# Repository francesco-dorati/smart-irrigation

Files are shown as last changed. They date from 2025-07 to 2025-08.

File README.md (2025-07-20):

# 🌿 Autonomous Plant Watering System

## Overview

This project aims to develop a **smart** and **autonomous** system for **watering indoor or outdoor plants**.  
The system is designed to **monitor soil moisture levels** and **automatically water** each plant when needed, making plant care effortless and reliable.

## 🌱 The Product

This system is designed to **take care of each plant separately** and **autonomously**.  
It provides **individualized watering** for each plant, ensuring they get exactly what they need—no more, no less.  
Perfect for balconies, gardens, or indoor setups.

1. **⚙️ Main Unit**  
   The central hub of the watering system, consisting of the **controller** and **water tank**.
   - 🪴 **Expandable** with up to **8 plants**  
   - 🔋 **Self-Sufficient** thanks to a **3500mAh battery**  
   - ☀️ **Solar Power** for complete autonomy

2. **🌿 Plant Unit**  
   A compact module attached to each plant, designed for **individual care**.
   - 📟 Composed of a **microcontroller**, **humidity sensor** and a **water pump**
   - 🔌 Connects to the Main Unit via an **Ethernet cable** and **water pipe**
   - 📏 Can be placed **up to 5 meters away** from the Main Unit

## 🚧 Project Status

- [x] Define system concept and design
- [x] Electrical scheme
- [x] Basic prototype
- [ ] Complete prototype with 1 plant
- [ ] Complete prototype with multiple plants
- [ ] Final enclosure design

## 📚 Resources
- ⚙️ Technical Details — [[here](docs/specifications.md)]
- 🧰  Components List — [[here](docs/components.md)]
- ⚡  Electrical Schemes — [[Main Unit](hardware/schematics/main_scheme.png) | [Plant Unit](hardware/schematics/plant_scheme.png)]
    
## 🤝 Contributing

Contributions, feedback, and suggestions are welcome!  
If you'd like to collaborate, please contact me via email:

**📧 fd.francescodorati@gmail.com**

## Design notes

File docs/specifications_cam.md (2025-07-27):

# Final Demo

## Main Loop:
1. **LOAD DATA**  
   - If `plants.csv`, `history.csv` or `weather.csv` is not in RAM, load them from SD card.  

     - **weather.csv** fields:  
       - `date` (YYYY-MM-DD)  
       - `T_max` (°C), `T_min` (°C)  
       - `Rn` (MJ/m²·day), `RH` (%)  
       - `u2` (m/s)

2. **TURN ON PLANTS**  
   - Activate the main relay (`RELAY_ON`).

3. **FOR EACH PLANT**  

   1. **STATUS REQUEST**  
      - Send `STATUS` → receive `<ID> <humidity> <saucerEmpty>`.

   2. **WATERING DECISION**  
      - **If** `saucerEmpty == true` (state `ABSORBING`): 

        1. **Compute reference evapotranspiration (ET₀)** using FAO Penman–Monteith:
           ```
           ET_{0} =
           (0.408 * Δ * (Rn - G) + (900/(T + 273)) * γ * u2 * (es - ea))
           / (Δ + γ * (1 + 0.34 * u2))
           ```
           - T = (T_max + T_min)/2  
           - G ≈ 0 (daily balance)  
           - Δ, γ, es, ea computed from T and RH.  

        2. **Select crop coefficient Kc** based on `type` and growth stage (use mid‑season Kc_mid by default):

           type            | Photosynthesis | Kc_mid
           ----------------|----------------|-------
           SUCCULENT       | CAM            | 0.30
           MEDITERRANEAN   | C3 (dry‑adapt) | 0.60
           HOUSEPLANT      | C3 (indoor)    | 0.80
           FERN            | C3 (humid)     | 1.00
           VEGETABLE       | C3/C4          | 1.10

        3. **Compute crop evapotranspiration**:
           ```
           ETc = Kc * ET0   [mm/day]
           ```
        4. **Convert ETc to water volume (ml)**:  
           - If saucer area A (m²) is known:
             ```
             water_ml = ETc [mm] * A [m2] * 1000
             ```
           - Otherwise scale by `saucerCapacity`:
             ```
             water_ml = saucerCapacity * (ETc / ET_ref)
             ```
             with ET_ref = 5 mm/day (approx. one full saucer).

        5. **Decision**: if `humidity <= minHumidity`, send  
           `WATER <water_ml>`  
           and set state = `WATERING`.

      - **Else if** state == `WATERING`:  
        1. **Check stop condition**: if  
           `humidity >= optimalHumidity * 0.9`  
           then send `WATER 0` (or `RELAY_OFF`) to stop.  
        2. **(Optional)**: recalculate ETc and adjust `water_ml` if continuing.

   3. **LOG**  
      - Append to `history.csv`: timestamp, `id`, `action`, `description`.

4. **WAKEUP DECISION**  
   - Based on predicted ET₀ for coming days (hot/dry → more frequent cycles), schedule next RTC wakeup.

5. **DEEP SLEEP**  
   - Enter deep sleep until RTC.

## Memory Files:
- `plants.csv`
    - `id`: id of the plant
    - `name`: name of the plant
    - `type`: type of plant
    - `saucerCapacity`: capacity of the saucer    
- `history.csv`
    - `time`: date time stamp
    - `id`: plant id or `-` for Main Unit
    - `action`: between `STATUS`, `WATER`, `WAKEUP`, `SLEEP`, `RELAY_ON`, `RELAY_OFF`
    - `description`: description of the action (status, uptime, etc)
- weather.csv
    - `date`,
    - `T_max`,
    - `T_min`,
    - `Rn`,
    - `RH`,
    - `u2`.

## Watering Process:

### Per-plant Data
 - `humidity`: current plant humidity (percentage)
 - `saucerEmpty`: wether saucer is empty
 - `saucerCapacity`: water capacity (or time to fill) of the plant saucer [ml or seconds]

### Type of Plants
  `SUCCULENT`, `FERN`, `HOUSEPLANT`, `MEDITERRANEAN`, `VEGETABLE`  
  Each of these plant types determines the values for these variables:
  - `minHumidity`: minimum soil humidity -> starts watering when reached
  - `optimalHumidity`: optimal soil humidity -> stops watering when reached
### Plant States
- `WATERING`: plant is being gradually watered (until humidity reaches `optimalHumidity`)
- `ABSORBING`: plant is absorbing water (waiting for humidity to reach `minHumidity`)

### Other External Data
- `temperature` (T_max, T_min)
- `airHumidity` (RH)
- `Rn`, `u2`

/* 
### Watering Process
The watering process proceeds gradually by filling the saucer by a specific amount and waiting for the plant to absorb it.
1. `SAUCER CHECK`: Check if the saucer is empty to receive water
  - if `ABSORBING` state:
    1. `CHECK`: Plant needs to be watered if `humidity <= minHumidity`
    2. `CALCULATE`: The amount of water to add is `saucerCapacity * (optimalHumidity - humidity)*2`
  - if `WATERING` state:
    1. `CHECK`: Plant needs to stop the watering process if `humidity >= optimalHumidity * 0.9`
    2. `CALCULATE`: The amount of water to add is `saucerCapacity * (optimalHumidity - humidity)*2`
*/

## Interfaces
- CLI -> Main Unit 
  - `INFO`: local info (without switching on plants)
  - `STATUS`: info about memory, and for each plant list current humidity and last watered time
  - `PLANT LIST`: list plants
  - `PLANT NEW`: new plant
  - `PLANT REMOVE`: remove plant
  - `PLANT INFO <id>`: prints local plant info
  - `PLANT STATUS <id>`: pings plant
  - `PLANT WATER <id>`: checks if plant needs water and if so waters it
    
- Main Unit -> Plant Unit
  - Status reading:  
      `STATUS` -> `<ID> <humidity> <saucerEmpty>`
  - Watering command:  
    `WATER <ml>` -> `<ID> DONE`
  - Humidity calibration  
    `HUMIDITY_CALIBRATION` -> `<ID> <sensor_voltage> <sensor_value>` 
  - Saucer capacity calibration:  
      `CAPACITY_CALIBRATION` -> `<ID> [OK/KO]`
    - Start calibration: `START`
    - Stop calibration: `STOP` -> `<ID> <ml>`        

## Future Predictions & AI
- Water consumption: use daily ETc to predict volumes.
- Saucer absorption: model rate based on T and RH.
- AI extensions: time-series ML or reinforcement learning for
optimization.

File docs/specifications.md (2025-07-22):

# Final Demo

## Main Loop:
1. `LOAD DATA`: if memory is empty load data from SD card
2. `TURN ON PLANTS`: turn the main realy on
3. for each plant:
    1. `STATUS REQUEST`: request plant status
    2. `WATERING DECISION`: decide if and how much water the plant
    3. `LOG`: log activities in `history.csv`
4. `WAKEUP DECISION`: decide when to wake up next
5. `DEEP SLEEP`: deep sleep until RTC wakeup call 

## Memory Files:
- `plants.csv`
    - `id`: id of the plant
    - `name`: name of the plant
    - `type`: type of plant
    - `saucerCapacity`: capacity of the saucer    
- `history.csv`
    - `time`: date time stamp
    - `id`: plant id or `-` for Main Unit
    - `action`: between `STATUS`, `WATER`, `WAKEUP`, `SLEEP`, `RELAY_ON`, `RELAY_OFF`
    - `description`: description of the action (status, uptime, etc)

## Watering Process:

### Data for each Plant
 - `humidity`: current plant humidity (percentage)
 - `saucerEmpty`: wether saucer is empty
 - `saucerCapacity`: water capacity (or time to fill) of the plant saucer [ml or seconds]

### Type of Plants
  `SUCCULENT`, `FERN`, `HOUSEPLANT`, `MEDITERRANEAN`, `VEGETABLE`  
  Each of these plant types determines the values for these variables:
  - `minHumidity`: minimum soil humidity -> starts watering when reached
  - `optimalHumidity`: optimal soil humidity -> stops watering when reached
### Plant States
- `WATERING`: plant is being gradually watered (until humidity reaches `optimalHumidity`)
- `ABSORBING`: plant is absorbing water (waiting for humidity to reach `minHumidity`)

### Other External Data
- `temperature`: outside temperature
- `airHumidity`: outside air humidity

### Watering Process
The watering process proceeds gradually by filling the saucer by a specific amount and waiting for the plant to absorb it.
1. `SAUCER CHECK`: Check if the saucer is empty to receive water
  - if `ABSORBING` state:
    1. `CHECK`: Plant needs to be watered if `humidity <= minHumidity`
    2. `CALCULATE`: The amount of water to add is `saucerCapacity * (optimalHumidity - humidity)*2`
  - if `WATERING` state:
    1. `CHECK`: Plant needs to stop the watering process if `humidity >= optimalHumidity * 0.9`
    2. `CALCULATE`: The amount of water to add is `saucerCapacity * (optimalHumidity - humidity)*2`
       
## Interfaces
- CLI -> Main Unit 
  - `INFO`: local info (without switching on plants)
  - `STATUS`: info about memory, and for each plant list current humidity and last watered time
  - `PLANT LIST`: list plants
  - `PLANT NEW`: new plant
  - `PLANT REMOVE`: remove plant
  - `PLANT INFO <id>`: prints local plant info
  - `PLANT STATUS <id>`: pings plant
  - `PLANT WATER <id>`: checks if plant needs water and if so waters it
    
- Main Unit -> Plant Unit
  - Status reading:  
      `STATUS` -> `<ID> <humidity> <saucerEmpty>`
  - Watering command:  
    `WATER <ml>` -> `<ID> DONE`
  - Humidity calibration  
    `HUMIDITY_CALIBRATION` -> `<ID> <sensor_voltage> <sensor_value>` 
  - Saucer capacity calibration:  
      `CAPACITY_CALIBRATION` -> `<ID> [OK/KO]`
    - Start calibration: `START`
    - Stop calibration: `STOP` -> `<ID> <ml>`        

## Preditions:
- predict water consumption by plant, given plant info and temperature
- predict saucer water absobtion given outside temperature, humidity

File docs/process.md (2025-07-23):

## Operative Process:
1. Test current setup with MOSFET instead of relay
2. Finalize Plant Unit design
3. Main Unit breadboard setup
4. Testig and logic implementations
5. Finalize Main Unit design
6. PCB design

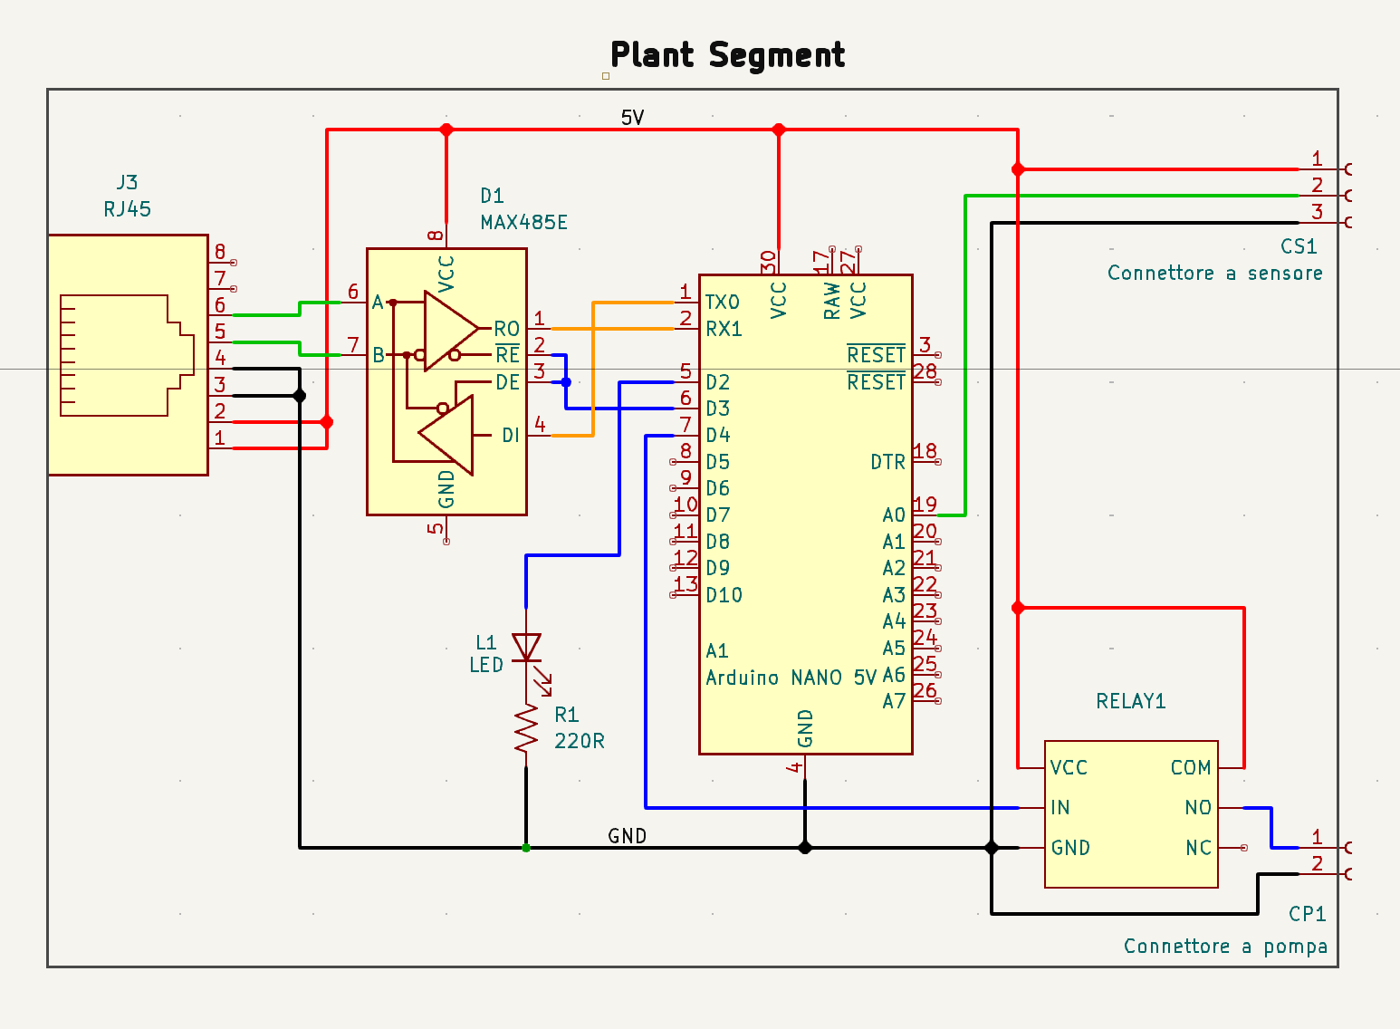
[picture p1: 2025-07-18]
hardware/schematics/plant_scheme.png

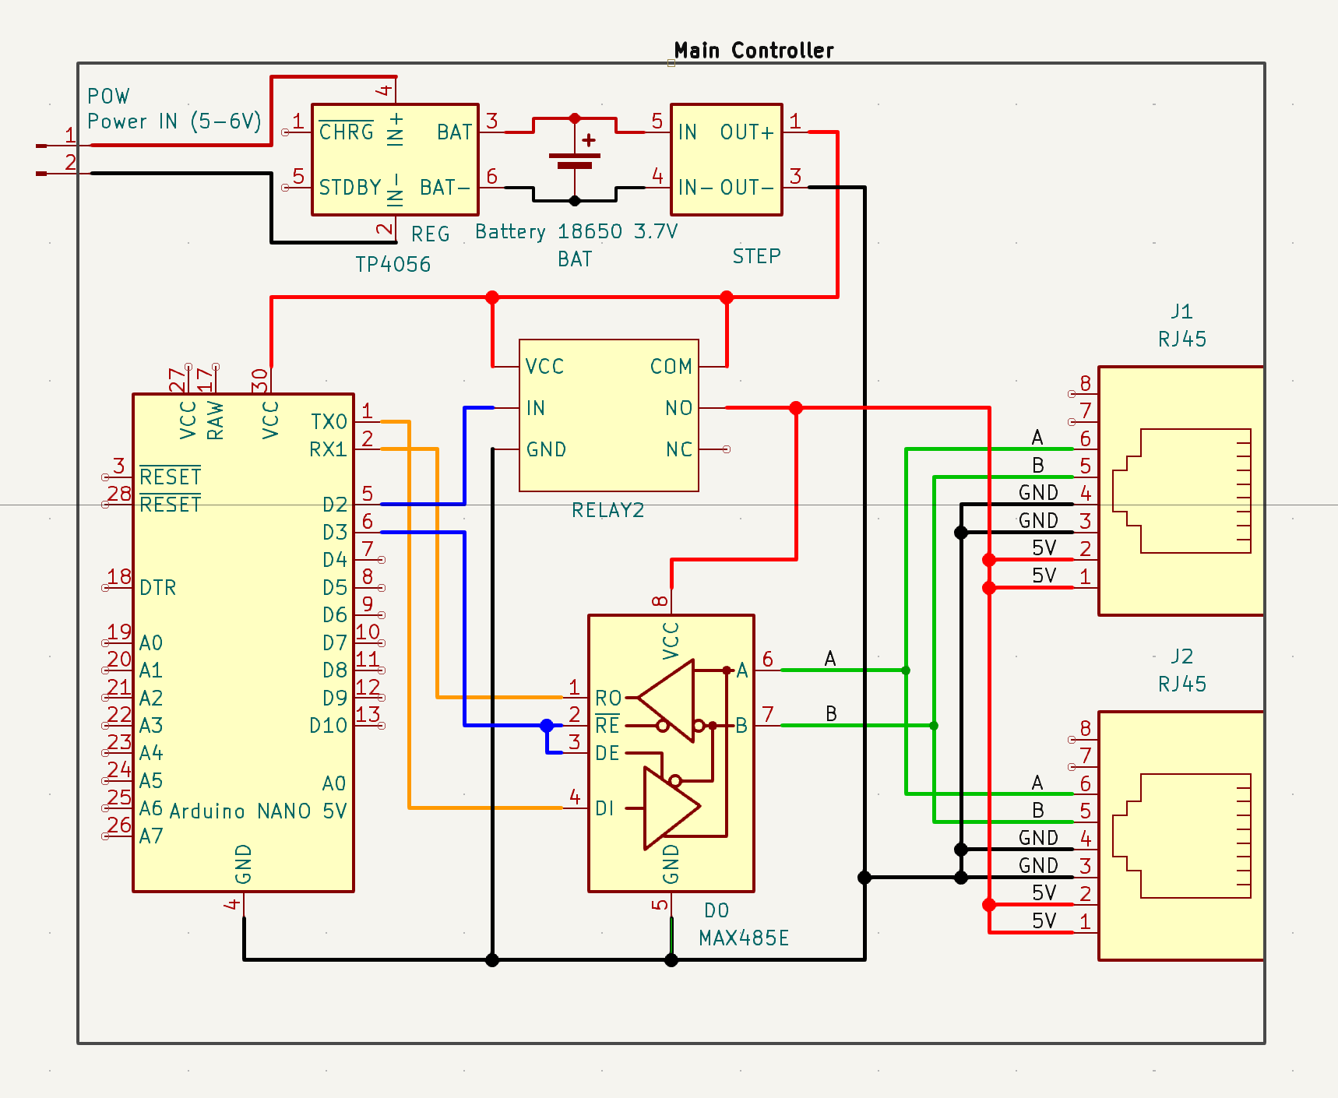
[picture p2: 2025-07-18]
hardware/schematics/main_scheme.png

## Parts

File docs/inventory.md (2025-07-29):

### Order 1 [06/07/2025]
- 5x Humidity Sernsor 
- 1x Pump
- 1x USB-Serial Converter
- 1x Ethernet Cable
- 2x Pro Mini Microcontroller 3.3V
- 2x Ethernet Adapter
- 10x MAX485 Connection Module
- **subtotal: 20€**

### Order 2 [20/07/2025]
- 1x RTC Module
- 5x Battery Charger Module TP4056
- 1x Relay Module
- 4x PCB Boards
- 1x ESP32 Board
- 5x DC-DC Step Up
- 1x Battery Support
- 1x Pipe
- 3x Ethernet Adapter
- 1x Battery 18560
- **subtotal: 38€**

### Order 3 [22/07/2025]
- 10x Screw Terminal 2-pin
- 10x Screw Terminal 3-pin
- 10x N MOSFET IRLZ44N
- 50x Diode 1N4007
- 300x Resistors (various)
- **subtotal: 12€**
  
### Order 4 [29/07/2025]
- 50x NPN MOSFET 2N2222
- 10x P MOSFET IRF4905
- **subtotal: 14€**

---
### Total Euro: 84€

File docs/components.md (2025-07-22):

# Components
TODO: Update the realy with mosfet
### **Per Pianta:**  

  → 4 cavi dal Main: 5V, GND, A, B  -> Cavo ETHERNET
- [ ]  1 Humidity Sensor analogical capacitive (3-5V, ? W, DC) [SZHJW]
- [ ]  1 Pump (3-5V, 0.91W max, DC)
- [ ]  1 Microcontroller Arduino NANO (5V, ? W, DC)
- [ ]  1 Relay Module [SRD-05VDC-SL-C]
- [ ]  1 Connection Module [MAX485 TTL]
- [ ]  1 Resistor 10k 
- [ ]  1 Cavo Ethernet 3m
- [ ]  1 Connettore Ethernet
- [ ]  1 Tubo acqua 

---

### **Control Unit:**

**Controller:**

- [ ]  1 Microcontroller ESP32 (5V, ? W, DC)
- [ ]  1 Connection Module [MAX485] 
- [ ]  1 MicroSD Module 
- [ ]  1 Relay Module [SRD-05VDC-SL-C]
- [ ]  1 Ethernet Connector
- [ ]  1 Temperature Sensor
- [ ]  1 RTC Module

**Power Management:**

- [ ]  1 Modulo caricatore batteria (5V, 1A, DC)[TP4056]
- [ ]  1/2 Batterie 18650  (3.7V, 2500–3000mAh)
- [ ]  1 Step-Up MT3608 (3.7V → 5V, 2A out max)

**Altro:**

- [ ]  1 Pannello solare (5-6V, 2W)

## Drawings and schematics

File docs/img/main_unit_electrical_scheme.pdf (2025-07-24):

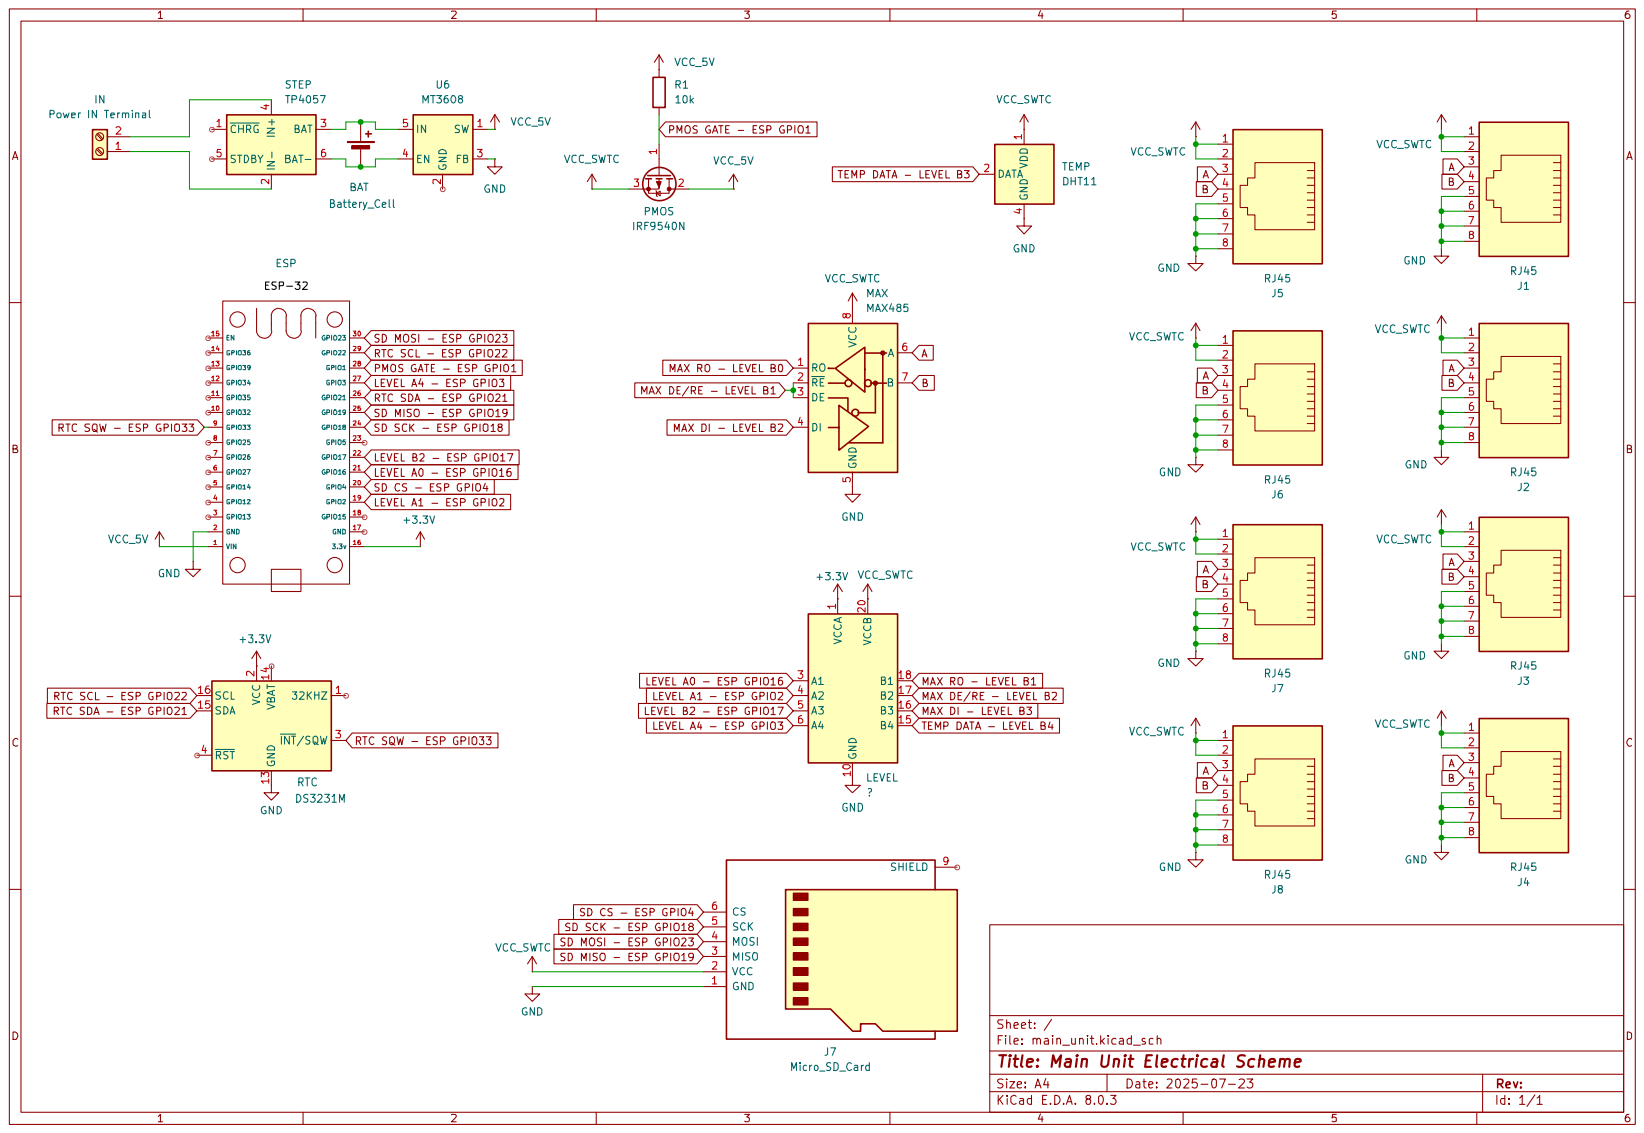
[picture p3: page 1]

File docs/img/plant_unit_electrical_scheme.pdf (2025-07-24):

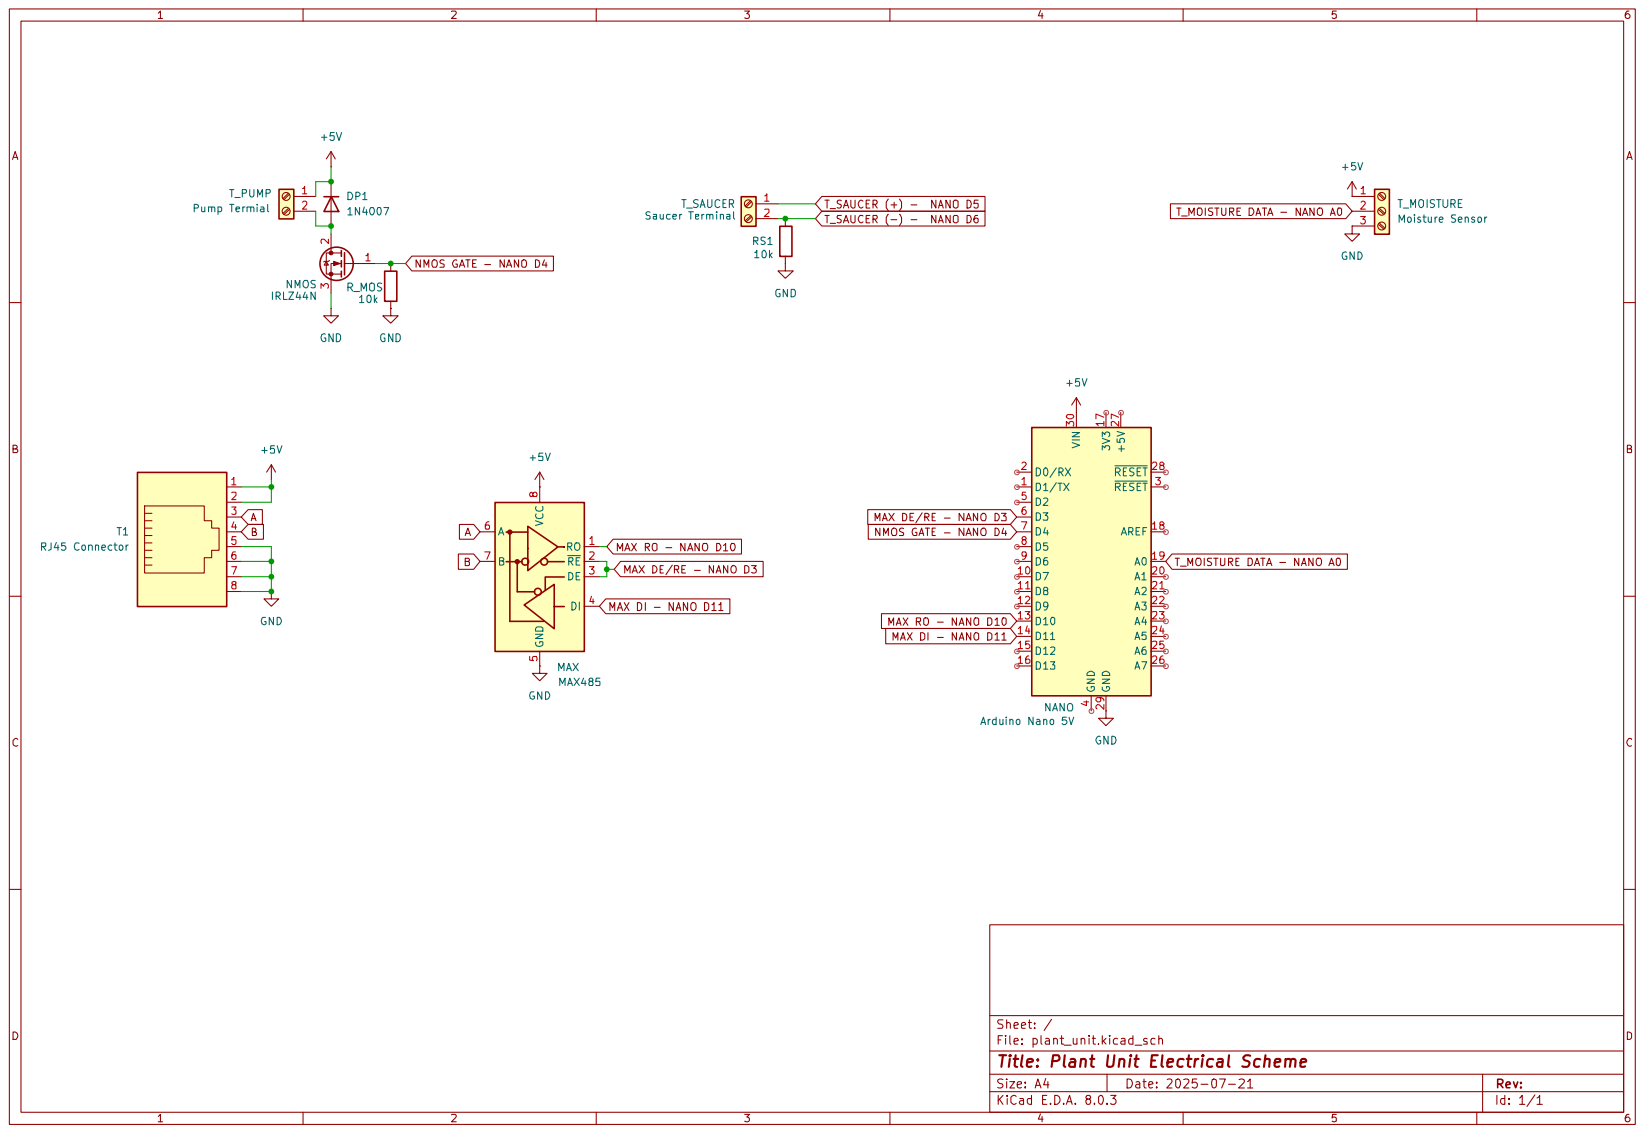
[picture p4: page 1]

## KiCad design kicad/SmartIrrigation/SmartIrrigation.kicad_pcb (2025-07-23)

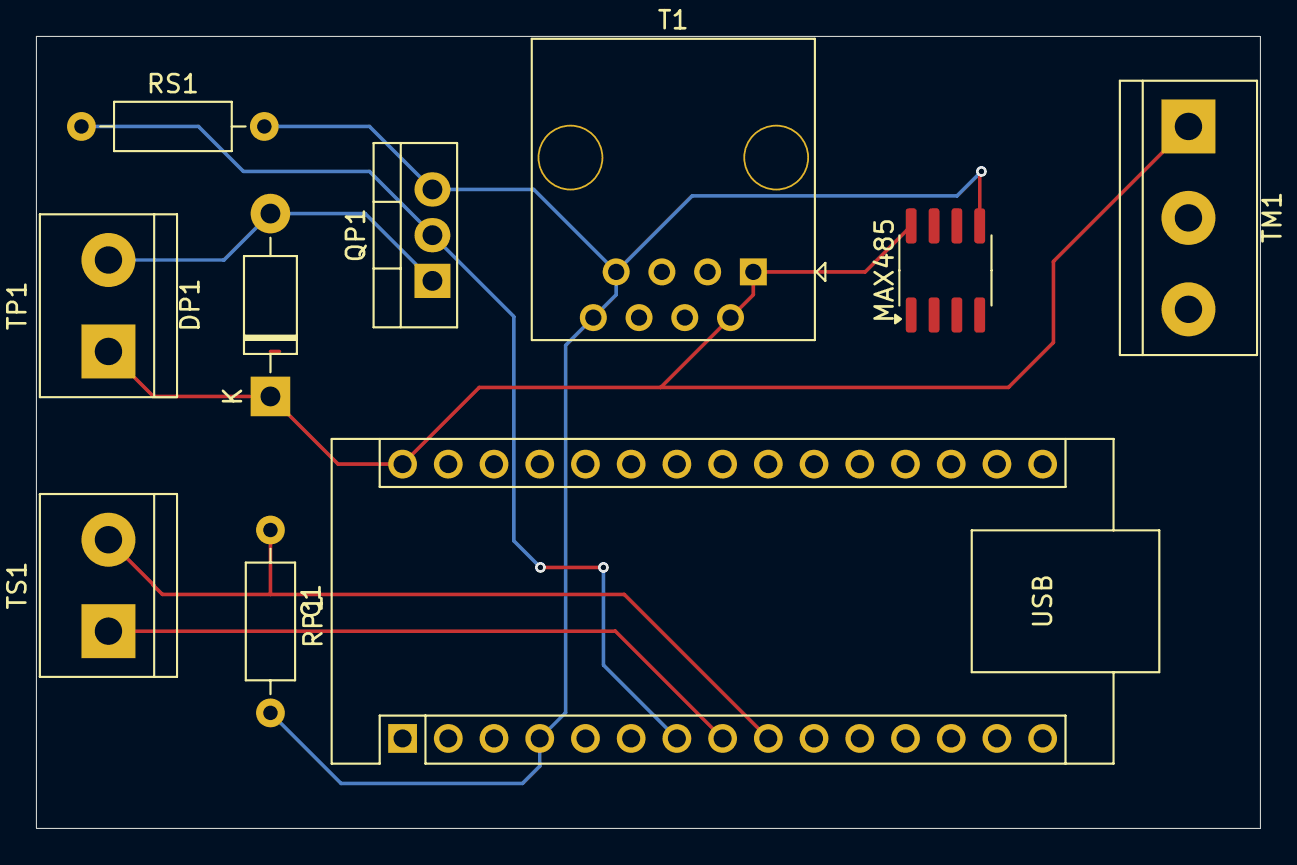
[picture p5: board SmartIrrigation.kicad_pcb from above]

Board: 2 copper layers, 68.0 x 44.0 mm, 10 parts (0 on the bottom side), 12 nets.

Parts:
C1: Arduino Nano 5V; Arduino_Nano
DP1: 1N4007; D_DO-41_SOD81_P10.16mm_Horizontal
MAX485: Connection Module; SOIC-8_3.9x4.9mm_P1.27mm
QP1: IRLZ44N; TO-220-3_Vertical
RP1: 10k; R_Axial_DIN0207_L6.3mm_D2.5mm_P10.16mm_Horizontal
RS1: 10k; R_Axial_DIN0207_L6.3mm_D2.5mm_P10.16mm_Horizontal
T1: RJ45 Connector; RJ45_OST_PJ012-8P8CX_Vertical
TM1: Moisture Sensor; TerminalBlock_bornier-3_P5.08mm
TP1: Pump Termial; TerminalBlock_bornier-2_P5.08mm
TS1: Saucer Terminal; TerminalBlock_bornier-2_P5.08mm

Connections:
+5V: C1.30 (VIN), DP1.1 (K), MAX485.8 (VCC), T1.1, T1.2, TM1.1, TP1.1
GND: C1.4 (GND), MAX485.5 (GND), QP1.3 (S), RP1.2, RS1.2, T1.7, T1.8, TM1.3
unnamed: C1.19 (A0), TM1.2
unnamed: C1.6 (D3), MAX485.2 (~RE), MAX485.3 (DE)
unnamed: C1.7 (D4), QP1.2 (D), RS1.1
unnamed: C1.8 (D5), TS1.1
unnamed: C1.9 (D6), RP1.1, TS1.2
unnamed: C1.13 (D10), MAX485.1 (RO)
unnamed: C1.14 (D11), MAX485.4 (DI)
unnamed: DP1.2 (A), QP1.1 (G), TP1.2
unnamed: MAX485.6 (A), T1.3
unnamed: MAX485.7 (B), T1.4

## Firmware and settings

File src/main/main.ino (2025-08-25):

#include <Arduino.h>
#include <ArduinoOTA.h>

#include "Controller.h"
#include "WiFiManager.h"

WiFiManager wifi("iPhone di Francesco", "grinder420");
Controller controller(wifi);

void setup() {
  Serial.begin(115200);
  wifi.begin();
  delay(2000);
  controller.init();
  delay(1000);

  ArduinoOTA.setHostname("smart-irrigation"); // Optional
  ArduinoOTA.begin();

  wifi.println("\n\n\n--- SMART IRRIGATION ---\n");
  status();
  help();
  prompt();
}

void loop() {
  ArduinoOTA.handle();

  // Serial command
  if (Serial.available()) {
    String command = readCommand();
    if (!command.equals("")) {
      interpretUserCommand(command);
    }
  }

  if (wifi.available()) {
    String command = wifi.getCommand();
    if (!command.equals("")) {
      interpretUserCommand(command);
    }
  }
}

String readCommand() {
    String command = Serial.readStringUntil('\n');
    command.trim();
    command.toUpperCase(); 
    return command;
}

void interpretUserCommand(String command) {
  wifi.println("");
  String a0 = getArg(command, 0);
  if (a0.equals("PLANT") || a0.equals("P")) {

    String a1 = getArg(command, 1);
    if (a1.equals("NEW") || a1.equals("N")) {  // PLANT NEW <id> <name>
      // ON command (sd)
      newPlant();

    } else if (a1.equals("LIST") || a1.equals("L")) {  // PLANT LIST
      // OFF command
      listPlants();

    } else if (a1.equals("INFO") || a1.equals("I")) {  // PLANT INFO <id>
      // OFF command
      int plantId = getArg(command, 2).toInt();
      infoPlant(plantId);

    } else if (a1.equals("STATUS") || a1.equals("S")) {  // PLANT STATUS <id> 
      int plantId = getArg(command, 2).toInt();
      statusPlant(plantId);

    } else if (a1.equals("WATER") || a1.equals("W")) {  // PLANT WATER <id>
      int plantId = getArg(command, 2).toInt();
      waterPlant(plantId);

    } else {
      help();
    }

  } else if (a0.equals("STATUS") || a0.equals("S")) {
    status();

  } else if (a0.equals("INFO") || a0.equals("I")) {
    info();

  } else if (a0.equals("ON") || a0.equals("1")) {
    wifi.println("Powering ON");
    controller.turnOn();

  } else if (a0.equals("OFF") || a0.equals("0")) {
    wifi.println("Powering OFF");
    controller.turnOff();

  } else if (a0.equals("SLEEP") || a0.equals("Z")) {
    int sleepTime = getArg(command, 1).toInt();
    if (sleepTime <= 0) {
      wifi.println("Invalid sleep time. Please specify a positive number.");
      return;
    }
    controller.sleep(sleepTime);

  } else {
    help();
  }

  prompt();
}

String getArg(String command, int argIndex) {
  for (int i = 0; i <= argIndex; i++) {
    int spaceIndex = command.indexOf(' ');
    if (spaceIndex == -1) {
      if (i == argIndex)
        return command;  // Last argument
      else
        return "";  // Not enough arguments
    }
    if (i == argIndex) {
      return command.substring(0, spaceIndex);
    }
    command = command.substring(spaceIndex + 1);
  }
  return "";
}



// SERIAL DEBUG COMMANDS
void newPlant() {
  wifi.println("\n\n--- PLANT CREATION ---\n");

  // ID
  int plantId;
  wifi.println("\nPlease enter the plant ID: ");
  while (!wifi.available());
  String plantIdString = wifi.getCommand();
  plantId = plantIdString.toInt();

  // NAME
  String plantName;
  wifi.println("\nPlease enter the plant name: ");
  while (!wifi.available());
  plantName = wifi.getCommand();

  // TYPE (WATER PREFERENCE)
  WaterPreference waterPreference;
  int typeCount = sizeof(WaterPreference::allTypes) / sizeof(WaterPreference*);
  int typeSelection;
  do {
    wifi.println("\nPlease choose the plant type:");
    for (int i = 1; i <= typeCount; i++) {
      const WaterPreference* type = WaterPreference::allTypes[i-1];
      wifi.println("\t[" + String(i) + "] " + type->toString() + 
                   " (Min: " + String((int)type->minHumidity) + "%, Optimal: " + String((int)type->optimalHumidity) + "%)");
    }
    wifi.println("\t[0] CUSTOM");

    wifi.println("\nEnter the number corresponding to the plant type: ");
    while (!wifi.available());
    String typeSelectionString = wifi.getCommand();
    typeSelection = typeSelectionString.toInt();
  } while (typeSelection < 0 || typeSelection > typeCount);

  if (typeSelection == 0) {
    // CUSTOM type selected
    // min humidity
    wifi.println("\nPlease enter the minimum humidity value (in %): ");
    while (!wifi.available());
    String minHumidityString = wifi.getCommand();
    float minHumidity = minHumidityString.toFloat();
    // optimal humidity
    wifi.println("\nPlease enter the optimal humidity value (in %): ");
    while (!wifi.available());
    String optimalHumidityString = wifi.getCommand();
    float optimalHumidity = optimalHumidityString.toFloat();
    // preference creation
    waterPreference = WaterPreference(minHumidity, optimalHumidity, "CUSTOM");
  } else {
    // preference selection
    waterPreference = *WaterPreference::allTypes[typeSelection - 1];
  }

  // SAUCER CAPACITY
  int saucerCapacity;
  // @TODO SAUCER CAPACITY TEST
  wifi.println("\nPlease enter the saucer capacity (in ml): ");
  while (!wifi.available());
  String saucerCapacityString = wifi.getCommand();
  saucerCapacity = saucerCapacityString.toInt();

  // PLANT OVERVIEW
  wifi.println("\n--- PLANT OVERVIEW ---\n");
  wifi.println("ID: " + String(plantId));
  wifi.println("Name: " + plantName);
  wifi.println("Type: " + waterPreference.toString() + 
               " (Min: " + String((int)waterPreference.minHumidity) + "%, Optimal: " + String((int)waterPreference.optimalHumidity) + "%)");
  wifi.println("Saucer Capacity: " + String(saucerCapacity) + " ml");

  // CONFIRMATION
  wifi.println("\nDo you want to proceed with the creation? (y/n)");
  while (!wifi.available());
  String confirmation = wifi.getCommand();
  confirmation.toLowerCase();
  if (!confirmation.equals("y") && !confirmation.equals("yes")) {
    wifi.println("\nPlant creation cancelled.");
    return;
  }

  // PLANT CREATION
  bool ok = controller.addPlant(plantId, plantName, waterPreference, saucerCapacity);
  if (ok) {
    wifi.println("\nPlant created successfully!");
  } else {
    wifi.println("\nFailed to create plant.");
  }
}

void info() {
  wifi.println("\n--- SYSTEM INFO ---\n");
  wifi.println("SD Card: " + String(controller.getSDCard().getFreeSpace()) + " GB free (" + String(controller.getSDCard().getTotalSpace()) + " GB total)");
  wifi.println("Current time: " + controller.getReadableTimeString());
  wifi.println("Battery: -- %");
  wifi.println("Uptime: -- min");
  wifi.println("\nYOUR PLANTS:");
  Plant** plants = controller.getPlants();
  for (int i = 0; i < MAX_PLANTS; i++) {
    if (plants[i] != nullptr) {
      String infoString = controller.getPlantInfoString(plants[i]->getId());
      wifi.println(infoString);
    }
  }
}

void statusPlant(int id) {
  String statusString = controller.getPlantStatusString(id);
  wifi.println(statusString);
}

void infoPlant(int id) {
  String infoString = controller.getPlantInfoString(id);
  wifi.println(infoString);
}

void waterPlant(int id) {
  Plant* plant = controller.getPlant(id);
  if (plant == nullptr) {
    wifi.println("Plant " + String(id) + " not found");
    return;
  }

  wifi.println("Watering " + plant->getName() + "...");
  bool ok = plant->water(30);
  if (ok) {
    wifi.println("Watering completed successfully");
  } else {
    wifi.println("Failed to water " + plant->getName());
  }
}

void status() {
  wifi.println("\n--- STATUS ---\n");
  wifi.println(controller.getEnvironmentDataString()+"\n");
  wifi.println("YOUR PLANTS:");
  Plant** plants = controller.getPlants();
  for (int i = 0; i < MAX_PLANTS; i++) {
    if (plants[i] != nullptr) {
      String statusString = controller.getPlantStatusString(plants[i]->getId());
      wifi.println(statusString);
    }
  }
}

void help() {
  wifi.println("\n--- AVAILABLE COMMANDS ---\n");
  wifi.println("\tINFO - Show local information (battery, uptime, etc.)");
  wifi.println("\tON/OFF - Turn on/off the system");
  wifi.println("\tSTATUS - Show the status of all plants");
  wifi.println("\tSLEEP <sec> - Put the system to sleep for a specified number of seconds");
  //Serial.println("");
  wifi.println("\tPLANT LIST - List all plants");
  wifi.println("\tPLANT NEW - Create a new plant");
  wifi.println("\tPLANT REMOVE <id> - Remove plant with the given id");
  wifi.println("\tPLANT INFO <id> - Get information about a specific plant");
  wifi.println("\tPLANT STATUS <id> - Get the status of a specific plant");
  wifi.println("\tPLANT WATER <id> - Water a specific plant");
}

void prompt() {  
  String s = "\n";
  s += controller.getReadableTimeString();
  
  s += " | Power ";
  s += controller.isOn() ? "ON" : "OFF";
  
  s += " | WiFi ";
  s += wifi.isConnected() ? "CONNECTED" : "DISCONNECTED";

  s += "\n> ";

  wifi.print(s);

}

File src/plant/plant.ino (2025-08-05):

#include <Arduino.h>

#include "HumiditySensor.h"
#include "LED.h"
#include "Pump.h"
#include "RS485Client.h"
#include "SaucerSensor.h"

const int PLANT_ID = 0;  // Unique ID for this plant

const int SENSOR_PIN = A0;
const int LED_PIN = 2;
const int COMM_PIN = 3;  // LOW: listening, HIGH: sending
const int PUMP_PIN = 4;  // LOW: ON, HIGH: OFF
const int SAUCER_POWER_PIN = 5; // OUTPUT LOW: POWER OFF, HIGH: POWER ON
const int SAUCER_READING_PIN = 6; // INPUT LOW: EMPTY, HIGH: FULL
const int RX_PIN = 11;   // RX pin for RS485
const int TX_PIN = 10;   // TX pin for RS485

RS485Client rs485(PLANT_ID, COMM_PIN, RX_PIN, TX_PIN);
LED led(LED_PIN);
HumiditySensor humiditySensor(SENSOR_PIN);
SaucerSensor saucerSensor(SAUCER_POWER_PIN, SAUCER_READING_PIN);
Pump pump(PUMP_PIN);

void setup() {
  Serial.begin(9600);

  rs485.begin(9600);
  led.begin();
  humiditySensor.begin();
  saucerSensor.begin();
  pump.begin();

  led.blink();
  led.blink();
  Serial.println("START");
  delay(1000);
}

void loop() {
  // RS485 communication
  if (rs485.available()) {
    // Read command from RS485
    String command = rs485.receiveCommand();
    if (!command.equals("")) {
      interpretCommand(command);
    }
  }

  // Serial communication (DEBUG)
  if (Serial.available()) {
    String command = Serial.readStringUntil('\n');
    Serial.println("debugging: \"" + command + "\"");
    interpretDebug(command);
  }
}

void interpretCommand(String command) {

  if (command.equals("PING")) {
    led.blink();
    rs485.transmit("PONG");

  } else if (command.startsWith("WATER")) {
    int seconds = command.substring(6).toInt();
    if (seconds < 0) return;  // Invalid command
    pump.activate(seconds);
    rs485.transmit("DONE");

  } else if (command.startsWith("STATUS")) { 
    float humidity = humiditySensor.getHumidity();
    bool full = saucerSensor.isFull();
    String status = String(humidity) + " " + (full ? "1" : "0");
    rs485.transmit(status);

  } else {
    Serial.println("Unknown command: \"" + command + "\"");
  }
}

void interpretDebug(String command) {
  if (command.equals("PING")) {
    led.blink();
    Serial.println("PONG");
  } else if (command.equals("HUMIDITY")) {
    int value = humiditySensor.getValue();
    float voltage = humiditySensor.getVoltage();
    int humidity = humiditySensor.getHumidity();
    Serial.println("Humidity: " + String(humidity) + "%, Voltage: " +
                   String(voltage) + "V, value: " + String(value));
  } else if (command.startsWith("WATER")) {
    int seconds = command.substring(6).toInt();
    if (seconds < 0) return;  // Invalid command
    pump.activate(seconds);
    Serial.println("Watering DONE.");
  } else {
    Serial.println("Unknown command: " + command);
  }
}

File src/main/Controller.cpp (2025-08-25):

#include "Controller.h"

Controller::Controller(WiFiManager& wifi_)
    : wifi(wifi_),
      isPowerOn(false),
      tempSensor(DHT_PIN, DHT11),
      rs485(COMM_PIN, RX_PIN, TX_PIN, 9600),
      sdCard(SD_CARD_CS_PIN, SD_CARD_SCK_PIN, SD_CARD_MISO_PIN,
             SD_CARD_MOSI_PIN) {}

void Controller::init() {
  pinMode(LED_BUILTIN, OUTPUT);
  pinMode(POWER_PIN, OUTPUT);          // Set pin to LOW to avoid floating state
  pinMode(SHIFTER_POWER_PIN, OUTPUT);  // Set pin to LOW to avoid floating state
  pinMode(RTC_WAKEUP_PIN, INPUT_PULLUP);
  pinMode(BUTTON_WAKEUP_PIN, INPUT);

  digitalWrite(LED_BUILTIN, LOW);
  digitalWrite(POWER_PIN, LOW);          // Ensure pin is LOW initially
  digitalWrite(SHIFTER_POWER_PIN, LOW);  // Ensure pin is LOW initially
  // RTC begin
  if (!rtc.begin()) {
    wifi.println("Couldn't find RTC");
    while (1);
  }
  if (rtc.lostPower()) {
    wifi.println("RTC lost power, setting the time!");
    // Set time only the first time or after battery loss
    rtc.adjust(DateTime(F(__DATE__), F(__TIME__)));
  }

  // /* remove */ plants[0] =
  //     new Plant(rs485, 0, "Test Plant", PlantState::ABSORBING,
  //               WaterPreference::MEDITERRANEAN, 100);
}

bool Controller::addPlant(int id, String name, WaterPreference waterPreference,
                          int saucerCapacity) {
  turnOn();
  // Check if plant with same ID already exists
  for (int i = 0; i < MAX_PLANTS; i++) {
    if (plants[i] != nullptr && plants[i]->getId() == id) {
      wifi.println("ERROR: Plant with ID " + String(id) + " already exists.");
      return false;
    }
  }

  // Find an empty slot for the new plant
  for (int i = 0; i < MAX_PLANTS; i++) {
    if (plants[i] == nullptr) {
      Plant* newPlant = new Plant(rs485, id, name, PlantState::ABSORBING,
                                  waterPreference, saucerCapacity);
      if (!newPlant->ping()) {
        wifi.println("ERROR: No response from plant with ID " + String(id));
        delete newPlant;  // Clean up
        return false;
      }
      plants[i] = newPlant;
      sdCard.addPlant(newPlant);  // Save to SD card
      return true;                // Successfully added
    }
  }

  wifi.println("ERROR: Maximum number of plants reached.");
  return false;  // No empty slot found
}

Plant* Controller::getPlant(int id) {
  turnOn();
  for (int i = 0; i < MAX_PLANTS; i++) {
    if (plants[i] != nullptr && plants[i]->getId() == id) {
      return plants[i];
    }
  }
  return nullptr;  // Plant not found
}

Plant** Controller::getPlants() {
  return plants;  // Return the array of plant pointers
}

bool Controller::isOn() { return isPowerOn; }

void Controller::turnOn() {
  pinMode(POWER_PIN, OUTPUT);  // Set pin to OUTPUT to control power
  digitalWrite(POWER_PIN, HIGH);

  pinMode(SHIFTER_POWER_PIN, OUTPUT);
  digitalWrite(SHIFTER_POWER_PIN, HIGH);

  // Allow some time for the power to turn on
  if (!isPowerOn) {
    // Powering on the system
    delay(2000);  // Allow some time for the power to stabilize
    rs485.start();
    tempSensor.begin();
    if (!sdCard.start()) {
      wifi.println("ERROR: SD Card not found!");
    }
    rtc.begin();
    delay(1000);
  }
  isPowerOn = true;
}

void Controller::turnOff() {
  digitalWrite(SHIFTER_POWER_PIN, LOW);  // Turn off power
  delay(10);

  digitalWrite(POWER_PIN, LOW);  // Turn off power
  delay(10);

  if (isPowerOn) {
    rs485.stop();
    sdCard.stop();
    pinMode(DHT_PIN, INPUT);
    digitalWrite(DHT_PIN, LOW);
    rtc.begin();  // Reinitialize RTC because sd card fails it
  }

  isPowerOn = false;
}

void Controller::sleep(int seconds) {
  turnOff();

  rtc_gpio_init((gpio_num_t)SHIFTER_POWER_PIN);
  rtc_gpio_set_direction((gpio_num_t)SHIFTER_POWER_PIN,
                         RTC_GPIO_MODE_OUTPUT_ONLY);
  rtc_gpio_set_level((gpio_num_t)SHIFTER_POWER_PIN, 0);

  rtc_gpio_init((gpio_num_t)POWER_PIN);
  rtc_gpio_set_direction((gpio_num_t)POWER_PIN, RTC_GPIO_MODE_OUTPUT_ONLY);
  rtc_gpio_set_level((gpio_num_t)POWER_PIN, 0);

  // Clear any existing alarms
  rtc.disableAlarm(1);
  rtc.clearAlarm(1);

  DateTime now = rtc.now();
  rtc.setAlarm1(now + TimeSpan(0, 0, 0, seconds), DS3231_A1_Second);

  // Configure wakeup from external pin
  esp_sleep_enable_ext0_wakeup(RTC_WAKEUP_PIN, 0);  // Wake when pin goes LOW
  esp_sleep_enable_ext1_wakeup((1ULL << BUTTON_WAKEUP_PIN),
                               ESP_EXT1_WAKEUP_ANY_HIGH);

  wifi.println("Going to sleep for " + String(seconds) + " seconds...");
  delay(1000);

  esp_deep_sleep_start();
}

SDCard& Controller::getSDCard() {
  return sdCard;
}

String Controller::getTimeString() {
  DateTime now = rtc.now();
  char buf[20];  // enough space for "yyyy-mm-dd hh:mm:ss"
  sprintf(buf, "%04d-%02d-%02d %02d:%02d:%02d", now.year(), now.month(),
          now.day(), now.hour(), now.minute(), now.second());
  return String(buf);
}

String Controller::getReadableTimeString() {
  DateTime now = rtc.now();
  const char* months[] = {"Jan", "Feb", "Mar", "Apr", "May", "Jun",
                          "Jul", "Aug", "Sep", "Oct", "Nov", "Dec"};
  char buf[50];  // enough space for "dd Month yyyy hh:mm"
  snprintf(buf, sizeof(buf), "%d %s %04d %02d:%02d", now.day(),
           months[now.month() - 1], now.year(), now.hour(), now.minute());
  return String(buf);
}

String Controller::getEnvironmentDataString() {
  turnOn();
  float humidity = tempSensor.readHumidity();
  float temperature = tempSensor.readTemperature();

  if (isnan(humidity) || isnan(temperature)) {
    return "Failed to read from DHT sensor!";
  }

  return "Temperature: " + String((int)temperature) +
         "°C\nAir Humidity: " + String((int)humidity) + "%";
}

String Controller::getPlantStatusString(int id) {
  turnOn();
  String s = "";
  Plant* plant = getPlant(id);
  if (plant == nullptr) {
    s += "\n\t\tCurrently OFFLINE.";
    return s;
  }

  bool status = plant->loadStatus();

  String humidity = String((int)(plant->getHumidity() * 100));
  String saucerFull = plant->isSaucerFull() ? "FULL" : "EMPTY";
  int waterNeeded = plant->checkWaterNeeds(plant->getHumidity());

  s += "\t- [" + String(plant->getId()) + "] " + plant->getName();
  if (status) {
    s += "\n\t\tHumidity: \t" + humidity + "%";
    s += "\n\t\tSaucer: \t" + saucerFull;
    s += "\n\t\tNeeds Water: \t" +
         ((waterNeeded > 0) ? "YES, " + String(waterNeeded) + " %" : "NO");
  } else {
    s += "\n\t\tCurrently OFFLINE.";
  }

  return s;
}
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

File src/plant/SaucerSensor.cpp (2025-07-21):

#include "SaucerSensor.h"

SaucerSensor::SaucerSensor(int powerPin, int readingPin)
    : powerPin(powerPin), readingPin(readingPin) {}

void SaucerSensor::begin() {
  pinMode(powerPin, OUTPUT);
  pinMode(readingPin, INPUT);
  digitalWrite(powerPin, LOW);
}

bool SaucerSensor::isFull() {
  digitalWrite(powerPin, HIGH);
  delay(100);
  bool full = digitalRead(readingPin) == HIGH;
  digitalWrite(powerPin, LOW);
  return full;
}

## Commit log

2025-06-29 created folders
    [scheme.kicad_sch]
2025-06-29 changed schema
    [scheme.kicad_sch]
2025-06-29 plant client schema almost complete
    [scheme.kicad_sch]
2025-06-29 base schematics added
    [scheme.kicad_sch]
2025-06-30 modified base schematics
2025-07-05 modified schematics
    [scheme.kicad_sch]
2025-07-17 created basic prototype
2025-07-18 saved schematics & formatted
    [scheme.kicad_sch]
2025-07-20 Refactor LED blink method and implement RTC and RS485 communication classes
2025-07-21 Add SaucerSensor class and electrical scheme for plant unit
    - Implemented SaucerSensor class with methods to initialize and check if the saucer is full.
    - Added initial electrical scheme for the plant unit in KiCad.
    [SmartIrrigation.kicad_pcb, SmartIrrigation.kicad_sch, main_unit.kicad_sch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]
2025-07-21 Modifica il tipo di ID da String a int in diverse classi e aggiorna i metodi di ricezione e trasmissione per riflettere il cambiamento
2025-07-23 Add SDCard class for managing plant data logging and loading
    - Created SDCard.cpp and SDCard.h files.
    - Implemented methods for loading plant data and logging various plant statuses.
    - Prepared the class for future expansion with additional functionalities.
    [SmartIrrigation.kicad_pcb, main_unit.kicad_sch, plant_unit.kicad_sch]
2025-07-24 added schematics images
    [main_unit.kicad_sch, plant_unit.kicad_sch]
2025-08-05 new schemes
    [main_unit.kicad_sch]
2025-08-11 Refactor Controller class and enhance WiFiManager functionality; add sleep feature and improve power management
    [main_unit.kicad_sch]
2025-08-11 updated schematics
    [main_unit.kicad_sch]
2025-08-25 Add SD card support
    [main_unit.kicad_sch]
